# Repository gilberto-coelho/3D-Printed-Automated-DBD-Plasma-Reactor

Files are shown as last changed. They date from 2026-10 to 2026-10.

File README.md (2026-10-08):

# 3D-Printed Automated DBD Plasma Reactor

A custom **3D-printed automation system** developed for a laboratory-built **Dielectric Barrier Discharge (DBD) plasma reactor**, used in plasma-mediated vapor generation (PMVG) coupled to atomic absorption spectrometry (AAS).

The system integrates a **servo-actuated sample sealing mechanism**, **contactless infrared temperature monitoring**, and **Arduino-based control** to automate plasma operation, minimize mercury vapor losses, and improve analytical workflow.

The complete system, including **3D mechanical design, fabrication, electronics integration, Arduino programming, and automation**, was developed and implemented by me.

**Development:** 2024  
**Microcontroller:** Arduino Uno (ATmega328P)  
**Mechanical design:** Custom 3D-printed assembly  
**Programming:** Arduino C/C++  
**Application:** Automated PMVG-AAS instrumentation

**Complete automated DBD reactor:**

Automated DBD plasma reactor

<br>

## Overview

The project was developed to address two main challenges in DBD operation:

1. **Sample sealing:** liquid samples were manually introduced through a small opening in the quartz reactor, which needed to be sealed immediately to prevent analyte vapor losses during argon flow.
2. **Temperature monitoring:** conventional metallic temperature probes could cause unwanted electrical discharges near the high-voltage electrodes.

A compact 3D-printed assembly was designed to integrate the quartz reactor, MG90S servo motor, MLX90614 infrared thermometer, Arduino Uno, LCD, and electronic controls.

The resulting system provides:

- Automated sample inlet sealing using a servo motor and polyimide tape
- Contactless temperature measurement through an infrared sensor
- Automatic high-voltage power supply switching
- Optoelectronic isolation between the Arduino and power supply
- Real-time temperature and elapsed-time display on a 16×2 LCD
- Audible notifications for measurement completion and reactor cooling
- Servo calibration with EEPROM storage
- Push-button control and serial data output

<br>

## System Architecture

The **Arduino Uno** coordinates the mechanical movement, sensor acquisition, plasma switching, and user notifications.

```text
                     ┌──────────────────────┐
                     │      Arduino Uno     │
                     │       ATmega328P     │
                     └──────────┬───────────┘
                                │
         ┌──────────────────────┼──────────────────────┬───────────────────────┐
         │                      │                      │                       |
         ▼                      ▼                      ▼                       ▼
 ┌────────────────┐    ┌────────────────┐    ┌────────────────┐    ┌───────────────────────┐
 │   MG90S Servo  │    │    MLX90614    │    │    16×2 LCD    │    │ LED / Phototransistor │
 │                │    │    IR Sensor   │    │   I2C Display  │    │  Switching Interface  │
 │  Sealing Arm   │    │                │    │                │    └───────────────────────┘ 
 └────────────────┘    │  Temperature   │    │   Monitoring   │                │
                       └────────────────┘    └────────────────┘                ▼
                                                                   ┌──────────────────────┐
                                                                   │  High-Voltage Power  │
                                                                   │        Supply        │
                                                                   └──────────┬───────────┘
                                                                              │
                                                                              ▼
                                                                   ┌──────────────────────┐
                                                                   │      DBD Plasma      │
                                                                   └──────────────────────┘                     
```

<br>

## 3D Mechanical Design

A custom **3D-printed holder** was designed around the quartz reactor geometry to integrate the mechanical and electronic components into a compact assembly.

The structure accommodates the tubular quartz reactor, MG90S servo motor, movable sealing arm, polyimide tape, MLX90614 infrared sensor, Arduino Uno, 16×2 LCD, push-button, and buzzer.

Particular attention was given to **alignment of the sealing arm with the sample introduction opening** and positioning of the infrared sensor beneath the reactor.

### 3D CAD Model

**Complete CAD assembly:**

Complete CAD assembly

<br>
<br>

**3D-printed components:**

<table>
  <tr>
    <td width="50%">
      3D-printed components
    </td>
    <td width="50%">
      Assembled 3D-printed components
    </td>
  </tr>
</table>

<br>
<br>

## Servo-Actuated Sample Sealing Mechanism

A **MG90S servo motor** controls a movable arm that automatically seals the **2 mm sample introduction opening** in the quartz reactor.

- **Open position:** allows manual sample introduction using a micropipette.
- **Closed position:** presses the sealing surface against the reactor opening, minimizing argon leakage and mercury vapor losses.

The arm remains closed during plasma operation and subsequent cooling.

### Polyimide Tape Selection

**Polyimide tape** was wrapped around the sealing arm to provide a flexible contact surface compatible with the elevated temperatures and electrical environment of the DBD reactor.

The tape enables repeated opening and closing while maintaining the gas flow path. It was also used to cover the external copper electrodes, helping prevent unwanted electrical discharges through the surrounding air.

### Servo Calibration

The sealing position can be adjusted through the Arduino's push-button interface and stored in **EEPROM**, preserving the calibration after power-off.

The firmware uses servo `attach()` and `detach()` commands to avoid continuously driving the motor when movement is unnecessary.

**Sealing mechanism details:**

Servo-actuated sealing mechanism

<br>
<br>

## Contactless Temperature Monitoring

A **MLX90614 GY-906 infrared thermometer** was installed beneath the central region of the quartz reactor to measure temperature without physical contact.

This approach avoids the risk of external electrical discharges associated with metallic thermocouples near the high-voltage electrodes.

Temperature measurements are acquired through **I2C communication**, displayed on the LCD, transmitted via serial communication, and used to trigger an audible notification when the reactor reaches a predefined cooling threshold.

**Infrared sensor positioning:**

Infrared sensor positioning

<br>
<br>

**Temperature monitoring using argon or helium as discharge gas:**

<table>
  <tr>
    <td width="50%">
      Reactor temperature monitoring
    </td>
    <td width="50%">
      Temperature profiles
    </td>
  </tr>
</table>

<br>
<br>

## Automated Operation

The Arduino coordinates sample sealing, plasma switching, temperature monitoring, and audible notifications throughout the analytical procedure.

```text
Reactor ready (low temperature)
      ↓
Servo opens → Manual sample introduction
      ↓
Servo closes and seals the reactor
      ↓
Spectrometer acquisition begins
      ↓
High-voltage power supply ON
      ↓
DBD plasma → Mercury vapor generation and detection
      ↓
High-voltage power supply OFF
      ↓
Buzzer signals measurement completion
      ↓
Reactor cooling + Temperature monitoring
      ↓
Cooling threshold reached → Buzzer notification
      ↓
Ready for the next measurement
```

### Cooling Notification

After plasma operation, the Arduino continuously monitors the reactor temperature and activates a **buzzer** when the predefined cooling threshold is reached, notifying the operator that the reactor has cooled sufficiently.

In the provided firmware version, the threshold is **40 °C**, and the cooling notification is enabled only after the reactor temperature has first reached at least **100 °C**.

The buzzer also signals the completion of the programmed plasma operation time, reducing the need for continuous manual observation.

<br>

## High-Voltage Power Supply Integration

The reactor was connected to a **laboratory-built high-voltage power supply**, developed and assembled by me.

### Optoelectronic Switching

An **infrared LED and phototransistor interface** enables Arduino-controlled switching of the high-voltage power supply without a direct electrical connection between the control signal and the switching circuit.

This allows plasma activation and deactivation to be synchronized with the automated analytical procedure.

**Power supply schematic:**

High-voltage power supply schematic

<br>
<br>

For additional information about the electronic design, transformers, and development of these power supplies, see my related repository in GitHub:

**[High-Voltage Power Supplies for DBD Plasma](https://github.com/gilberto-coelho/High-Voltage-Power-Supplies-for-DBD-Plasma)**

<br>

## Internal Hardware

The Arduino, servo motor, infrared sensor, LCD, buzzer, push-button, and power supply switching interface were integrated into the 3D-printed assembly.

**Internal electronics and wiring:**

Internal electronics and wiring

<br>
<br>

### Arduino Connections

| Component | Arduino Pin | Function |
|---|---|---|
| MG90S servo motor | D9 | Sample inlet sealing |
| Buzzer | D5 | Audible notifications |
| High-voltage switching interface | D4 | Plasma ON/OFF control |
| Push-button | D7 | Operation and configuration |
| MLX90614 IR sensor | SDA (A4), SCL (A5) | Temperature monitoring |
| 16×2 LCD (I2C) | SDA (A4), SCL (A5) | Display and user interface |

The LCD (`0x27`) and MLX90614 share the **I2C bus**, while the push-button uses the Arduino's internal pull-up resistor (`INPUT_PULLUP`).

<br>

##Power Supply and Voltage Regulation

The entire system was powered by a 12 V / 2 A external power supply, connected directly to the Arduino Uno through its DC jack connector.

Since the Arduino Uno's onboard 5 V regulator cannot reliably supply the current required by the MG90S servo motor, a separate LM7805 linear voltage regulator was used to convert the 12 V input into 5 V for the servo.

This configuration provides:

- 12 V input: external power supply connected to the Arduino Uno.

- 5 V regulated output: LM7805 supplying the servo motor independently.

Common ground: Arduino, LM7805, and servo motor sharing the same GND reference.

Important: Do not power the servo motor directly from the Arduino Uno's 5 V pin. Servo motors can draw relatively high current, especially during startup or under mechanical load, potentially causing voltage drops, unexpected Arduino resets, or overheating of the onboard regulator.

<br>

## Firmware Development

The automation firmware was developed in **Arduino C/C++** for the ATmega328P microcontroller.

Its main features include:

- **Automated control:** coordination of the servo and plasma power supply.
- **Temperature acquisition:** MLX90614 measurements through I2C.
- **Servo calibration:** push-button adjustment with EEPROM storage.
- **Timed operation:** automatic plasma shutdown after **140 seconds** in the provided firmware.
- **Buzzer notifications:** measurement completion and cooling alerts.
- **LCD interface:** temperature, elapsed time, and configuration display.
- **Serial communication:** temperature and elapsed-time output at **9600 baud**.
- **Manual interruption:** push-button control to stop plasma operation.

The firmware uses the `Wire`, `LiquidCrystal_I2C`, `Servo`, `EEPROM`, and `Adafruit_MLX90614` libraries.

**Firmware:** [code.ino](code.ino)

<br>

## Operation Demonstration

**Plasma reactor operating with a liquid sample (without the automated system for better visualization):**

https://github.com/user-attachments/assets/d942ff1e-d814-4204-b4f6-3eddafce1815

<br>
<br>

**Servo-controlled opening and closing of the sample inlet:**

https://github.com/user-attachments/assets/96c73c88-e5cd-410f-9c77-6a471c6c0aa3

<br>
<br>

**Infrared camera monitoring of a similar reactor:**

https://github.com/user-attachments/assets/30fa5844-3035-44a5-a576-a9d7ddf0cf46

<br>
<br>

## Skills Demonstrated

- **3D CAD modeling and 3D printing:** custom mechanical design, fabrication, and assembly.
- **Mechanical integration:** servo-actuated mechanisms, alignment, and material selection.
- **Embedded programming:** Arduino C/C++, control logic, timers, and hardware interfacing.
- **Sensor integration:** I2C communication and infrared temperature monitoring.
- **Electronics:** servo control, LCD, buzzer, optoelectronic switching, and high-voltage system integration.
- **Data acquisition:** serial communication and temperature measurements.
- **EEPROM:** non-volatile storage of calibration parameters.
- **Laboratory automation:** integration of mechanical, electronic, and software systems.

<br>

## Research Publication

The design and application of this automated DBD system were reported in:

**Plasma-mediated mercury vapor generation after microwave-induced combustion of fish tissue with detection by atomic absorption spectrometry**

**Link:** https://doi.org/10.1016/j.sab.2024.107055

Further technical information, including the electronic schematic, component specifications, mechanical design, automation, and temperature monitoring, is available in the publication's **Supplementary Material**.

<br>

## Author

**Gilberto Coelho**  
Electronics & Automation Developer

I personally carried out the **complete development of this automation system**, including 3D CAD design, fabrication and assembly, electronic integration, Arduino firmware programming, and implementation of the automated control system.

The project was developed during my research activities in analytical chemistry.

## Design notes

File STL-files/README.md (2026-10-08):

3D-printable STL files for the automated DBD reactor.

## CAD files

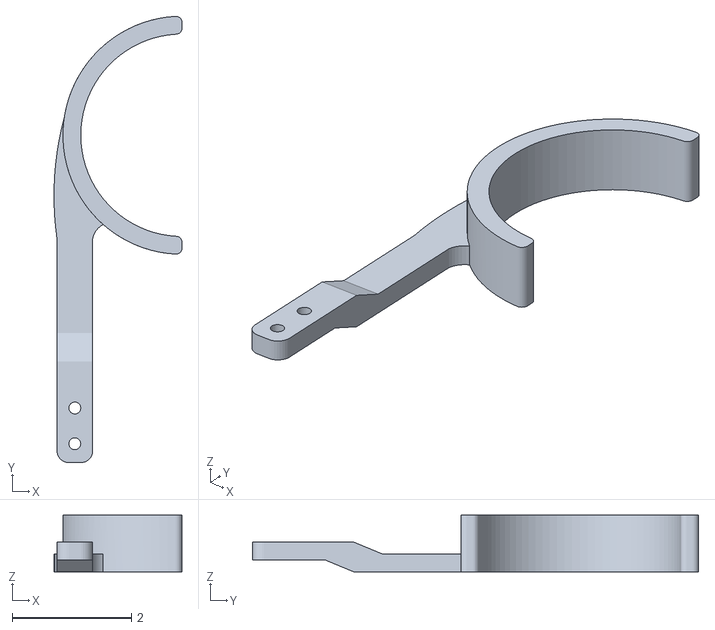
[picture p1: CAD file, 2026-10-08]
STL-files/Holder Tape.stl
2.15 x 7.50 x 0.95

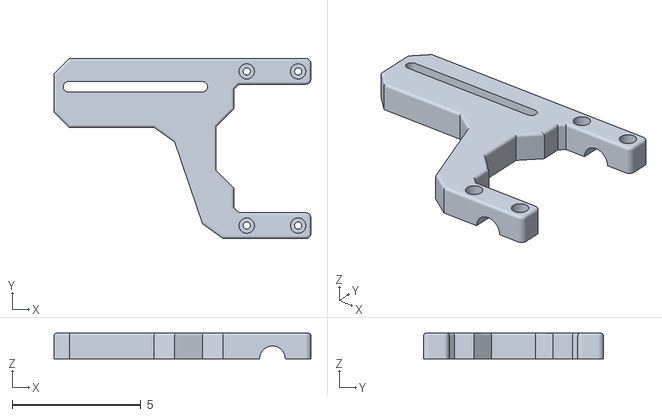
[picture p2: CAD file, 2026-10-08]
STL-files/Holder DBD TOP.stl
10.0 x 7.00 x 1.00

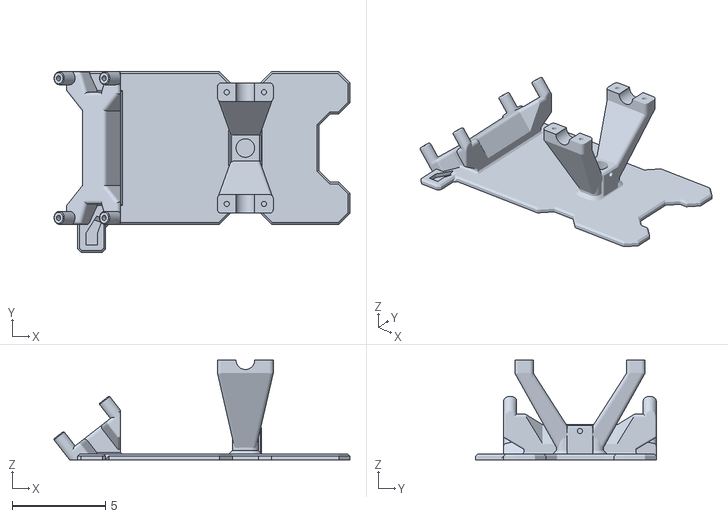
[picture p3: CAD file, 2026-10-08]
STL-files/Holder-DBD.stl
15.9 x 9.70 x 5.35

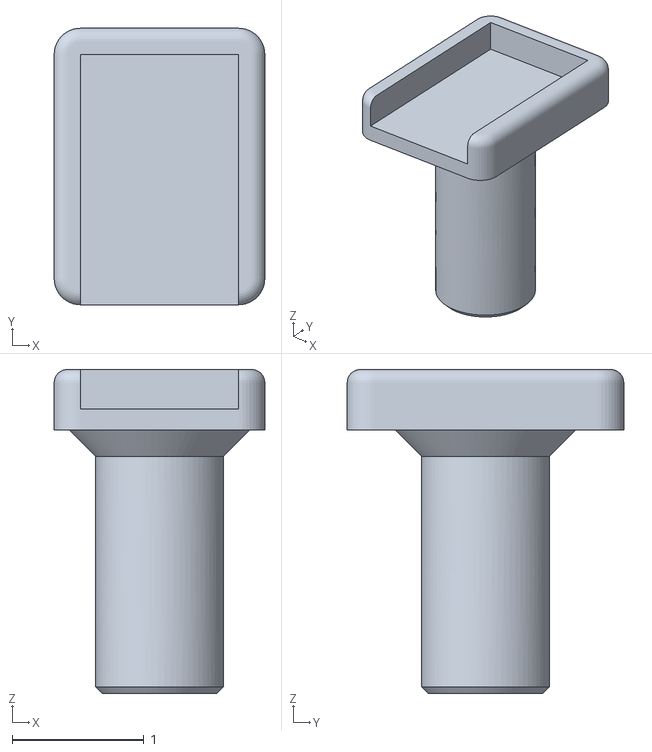
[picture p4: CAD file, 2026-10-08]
STL-files/Holder Sensor IR.stl
1.60 x 2.10 x 2.46

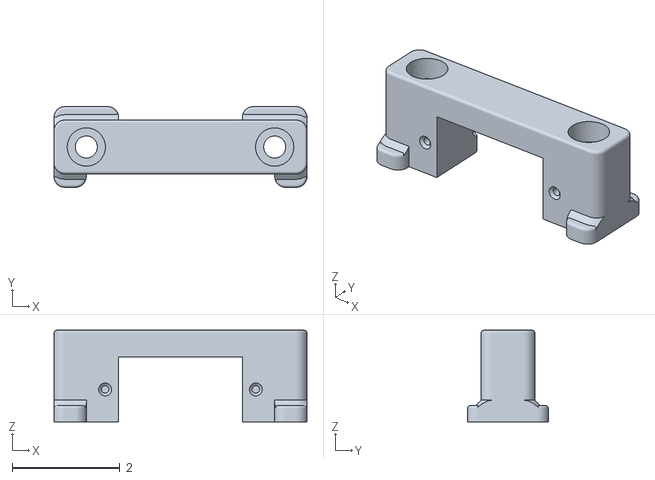
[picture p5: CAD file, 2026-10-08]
STL-files/Holder Servo.stl
4.70 x 1.50 x 1.70

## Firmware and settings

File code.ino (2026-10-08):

#include <Wire.h>
#include <LiquidCrystal_I2C.h>
#include <Servo.h>
#include <EEPROM.h>
#include <Adafruit_MLX90614.h>

Adafruit_MLX90614 mlx = Adafruit_MLX90614();

Servo myservo;
LiquidCrystal_I2C lcd(0x27, 16, 2);

uint8_t degree[8]  = {140, 146, 146, 140, 128, 128, 128, 128};

byte arrowDown[8] = {
  B00000,
  B00100,
  B00100,
  B11111,
  B11111,
  B01110,
  B00100,
  B00000
};

byte arrowUp[8] = {
  B00000,
  B00100,
  B01110,
  B11111,
  B11111,
  B00100,
  B00100,
  B00000
};

bool ajuste1 = 0;
bool ajuste2 = 0;
bool ajuste3 = 0;
bool ajuste4 = 0;
bool ajuste5 = 0;
bool ajuste6 = 0;

byte valorServo = 50;
byte memoriavalorServo = 1;

unsigned long tempo1 = 0;
unsigned long tempo2 = 0;

unsigned long tempo3 = 0;
unsigned long tempo4 = 0;

void aumenta();
void diminui();

int temperatura = 50;


void setup() {

  Serial.begin(9600);

  pinMode(7, INPUT_PULLUP); //Button
  pinMode(5, OUTPUT); // Buzzer
  pinMode(4, OUTPUT); // LED DBD

  digitalWrite(5, HIGH);
  delay(100);
  digitalWrite(5, LOW);
  digitalWrite(4, LOW);

  valorServo = EEPROM.read(memoriavalorServo);

  lcd.begin();
  lcd.backlight();
  lcd.createChar(0, degree);
  lcd.createChar(1, arrowDown);
  lcd.createChar(2, arrowUp);

  mlx.begin();

  lcd.setCursor(0, 0); lcd.print("Waiting..        ");
  lcd.setCursor(0, 1); lcd.print("Reactor:  "); lcd.print(mlx.readObjectTempC(), 0); lcd.print(" "); lcd.write((byte)0); lcd.print("C   ");

  myservo.attach(9);
  myservo.write(105); delay(500);
  myservo.detach();

}

void loop() {

  //Serial.print("Ambient = "); Serial.print(mlx.readAmbientTempC());
  //Serial.print("*C\tObject = "); Serial.print(mlx.readObjectTempC()); Serial.println("*C");
  //Serial.println();

  lcd.setCursor(0, 1); lcd.print("Reactor:  "); lcd.print(mlx.readObjectTempC(), 0); lcd.print(" "); lcd.write((byte)0); lcd.print("C   ");

  //delay(100);

  temperatura = mlx.readObjectTempC();
  if (temperatura >= 100) {
    ajuste4 = 1;
  }
  if (temperatura <= 40 && ajuste4 == 1) {
    digitalWrite(5, HIGH);
    delay(100);
    digitalWrite(5, LOW);
    delay(100);
    digitalWrite(5, HIGH);
    delay(100);
    digitalWrite(5, LOW);
    myservo.write(105); delay(500);
    myservo.detach();
    ajuste4 = 0;
  }


  if (digitalRead(7) == HIGH && ajuste1 == 0 && ajuste2 == 1) {
    myservo.attach(9);
    myservo.write(valorServo);
    ajuste1 = 1;
    ajuste2 = 0;
    ajuste5 = 1;
    ajuste6 = 0;
    tempo3 = millis();
  }



  if (ajuste5 == 1) {
    tempo4 = millis() - tempo3;
    Serial.print(tempo4); Serial.print(","); Serial.println(temperatura);
    tempo4 = tempo4 / 1000;
    lcd.setCursor(0, 0); lcd.print("Time: "); lcd.print(tempo4); lcd.print(" s  ");
    if (ajuste6 == 0) {
      delay(500);
    }
    ajuste6 = 1;
    digitalWrite(4, HIGH);
    if (digitalRead(7) == LOW) {
      while (digitalRead(7) == LOW) {;}
      myservo.write(105); 
      digitalWrite(4, LOW);
      delay(500);
      myservo.detach();
      tempo4 = 140;
    }
  }

  if (tempo4 >= 140) {
    digitalWrite(4, LOW);
    lcd.setCursor(0, 0); lcd.print("Waiting..        ");
    ajuste5 = 0;
    digitalWrite(5, HIGH);
    delay(100);
    digitalWrite(5, LOW);
    delay(100);
    digitalWrite(5, HIGH);
    delay(100);
    digitalWrite(5, LOW);
    tempo4 = 0;
  }

  if (digitalRead(7) == HIGH && ajuste1 == 1 && ajuste2 == 1) {
    digitalWrite(4, LOW);
    myservo.write(105); delay(500);
    myservo.detach();
    ajuste1 = 0;
    ajuste2 = 0;
    ajuste5 = 0;
    lcd.clear();
    lcd.setCursor(0, 0); lcd.print("Waiting..        ");

  }



  if (Serial.available() > 0) {
    valorServo = Serial.parseInt();
    valorServo = constrain(valorServo, 0, 180);
    myservo.attach(9);
    myservo.write(valorServo);
    Serial.print("Posição do Servo: ");
    Serial.println(valorServo);
  }




  if (digitalRead(7) == LOW) {
    if (ajuste2 == 0) {
      tempo1 = millis();
      ajuste2 = 1;
      ajuste1 = 0;
    }
    tempo2 = millis();
    if ((tempo2 - tempo1) > 1000) {
      ajuste2 = 0;
      while (digitalRead(7) == LOW) {
        lcd.clear();
      }
      while (digitalRead(7) == HIGH) {
        lcd.setCursor(0, 0); lcd.print("MENU      "); lcd.print(mlx.readObjectTempC(), 0); lcd.print(" "); lcd.write((byte)0); lcd.print("C   ");
        lcd.setCursor(0, 1); lcd.print("POSITION: "); lcd.print(valorServo); lcd.write((byte)0); lcd.print("  "); lcd.setCursor(15, 1); lcd.write((byte)1);
        myservo.attach(9);
        myservo.write(valorServo);
      }
      if (digitalRead(7) == LOW) {
        delay(1000);
        while (digitalRead(7) == LOW) {
          diminui();
        }
      }

      lcd.setCursor(0, 1); lcd.print("POSITION: "); lcd.print(valorServo); lcd.write((byte)0); lcd.print("  "); lcd.setCursor(15, 1); lcd.write((byte)2);
      while (digitalRead(7) == HIGH) {lcd.setCursor(0, 0); lcd.print("MENU      "); lcd.print(mlx.readObjectTempC(), 0); lcd.print(" "); lcd.write((byte)0); lcd.print("C   ");}

      if (digitalRead(7) == LOW) {
        delay(1000);
        while (digitalRead(7) == LOW) {
          aumenta();
        }
        EEPROM.put(memoriavalorServo, valorServo);
        lcd.clear();
        lcd.setCursor(0, 0); lcd.print("Wainting..    ");
        myservo.write(105); delay(500);
        myservo.detach();
        
      }
    }
  }
}

void diminui() {
  valorServo -= 1;
  lcd.setCursor(0, 1); lcd.print("POSITION: "); lcd.print(valorServo); lcd.write((byte)0); lcd.print("  "); lcd.setCursor(15, 1); lcd.write((byte)1);
  myservo.attach(9);
  myservo.write(valorServo);
  delay(1000);
}

void aumenta() {
  valorServo += 1;
  lcd.setCursor(0, 0); lcd.print("MENU      "); lcd.print(mlx.readObjectTempC(), 0); lcd.print(" "); lcd.write((byte)0); lcd.print("C   ");
  lcd.setCursor(0, 1); lcd.print("POSITION: "); lcd.print(valorServo); lcd.write((byte)0); lcd.print("  "); lcd.setCursor(15, 1); lcd.write((byte)2);
  myservo.attach(9);
  myservo.write(valorServo);
  delay(1000);
}
